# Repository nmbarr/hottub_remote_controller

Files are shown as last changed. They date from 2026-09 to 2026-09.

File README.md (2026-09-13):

# Hot Tub Remote Controller



Hardware and firmware for a remote monitor/controller that taps into a hot
tub's control system, aiming to expose status and control over WiFi instead
of only via the tub's built-in panel.

## Status

Early hardware design phase, **currently mid-pivot**. The tub's topside is a
Balboa VL240, and on GS-series packs that panel is not on an RS485 bus at
all: it is a dumb terminal on a 6-signal harness — four raw button contacts
plus a clock/data pair carrying the 7-segment display bitmap. See
[`docs/wifi.md`](docs/wifi.md#topside-panel-interface).

That invalidated the RS485 design this repo was originally built around.
Superseded and removed:

- `firmware/v1` — the from-scratch UART2 half-duplex driver, `0x7e` framer,
  and Balboa CRC-8. None of it described this tub, and it's been replaced
  by `firmware/esphome-spa`: a vendored, adapted fork of
  [kgstorm/Balboa-GS100-with-VL260-topside](https://github.com/kgstorm/Balboa-GS100-with-VL260-topside)
  (see [`firmware/esphome-spa/README.md`](firmware/esphome-spa/README.md)),
  which already implements the display-tap decode this tub's interface
  needs.
- The MAX3485 in `hardware/esp32-spa` (renamed from `hardware/v1`), and V2's
  plan to interpose between panel and pack. The board no longer sits *in*
  the harness; it hangs off it in parallel.

Still true: the ESP32 DevKitC, the RJ45 breakout so nothing gets spliced,
and the V2 antenna work. `firmware/esphome-spa` talks to Home Assistant
(running on the same Pi) rather than MQTT/Node-RED directly — see its own
README — though Mosquitto/Node-RED may still end up in the picture for
anything without an HA integration, like the planned pH/ORP sensors.

Nothing has been connected to the tub yet. The interface above is confirmed
for kgstorm's GS100; this pack is a Mach 7 (RS-81), and matching it is still
an inference from parts listings — see the read-only check in
[`docs/wifi.md`](docs/wifi.md#still-unconfirmed) before building.

## Hardware

`hardware/esp32-spa` (renamed from `hardware/v1`) contains the KiCad project
for the v1 board:

- **ESP32-DevKitC** as the main controller.
- **MAX3485** RS485 transceiver — **superseded**, see Status. The schematic
  has not been redrawn yet.

What replaces it: a passive tap on the topside harness. Two divided inputs
for the display clock and data, and four optocouplers to bridge the button
contacts without loading or backfeeding the panel, which stays wired in
parallel and has to keep working.

### Hardware diagram

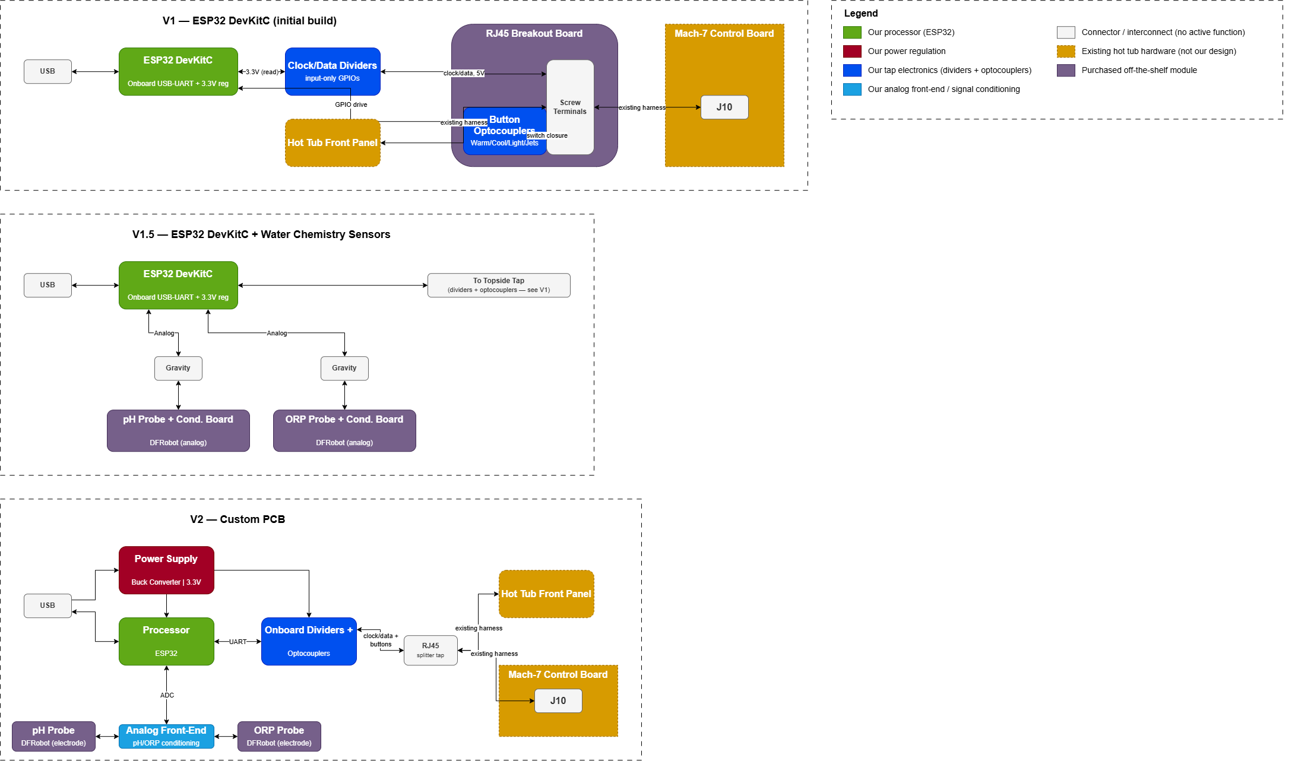
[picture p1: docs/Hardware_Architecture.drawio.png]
Hardware architecture


The three planned board revisions (v1, v1.5, v2 — see the roadmap below).

### Hardware roadmap

The hardware diagram lays out three planned revisions:

- **V1 — ESP32 DevKitC (initial build).** An ESP32 DevKitC (using its
  onboard USB-UART and 3.3V regulator) tapping the topside harness between
  the front panel and the Mach-7 control board, through an off-the-shelf
  RJ45 breakout board and screw terminals — no cutting or splicing of the
  existing harness. Two resistor-divided inputs read the display clock and
  data; four optocouplers bridge the button contacts. Build the read-only
  half first: it needs no optocouplers and touches nothing the pack can act
  on, so it proves the interface before anything can press a button.
- **V1.5 — + water chemistry sensors.** Same V1 hardware and same tap,
  with off-the-shelf DFRobot pH and ORP probes (each with its own analog
  conditioning board) added on, wired into the DevKitC's analog inputs via
  Gravity/JST connectors.
- **V2 — custom PCB.** Replaces the DevKitC with a purpose-built board: an
  ESP32-WROOM-32UE as the processor, a dedicated buck-converter power
  supply, and the dividers and optocouplers onboard. Note this no longer
  needs two RJ45 jacks in series: the board is a parallel tap, not an
  interposer, so one jack on a splitter off the existing harness does the
  job and keeps the panel working if the board is unplugged. The purchased
  DFRobot conditioning boards are also replaced by a custom analog front-end
  that conditions the raw pH and ORP electrodes directly for the ESP32's
  ADC.

#### Antenna

V2 uses the **WROOM-32UE**, the variant with a U.FL connector for an
external antenna, rather than the **-32E** with its PCB trace antenna.
Everything about the two is identical except the antenna, and the deciding
factor is where the board lives: a spa equipment bay is water on all sides,
several inches of foam insulation, a sealed enclosure the board cannot work
without, and an AP that is inside the house through at least one exterior
wall.

Marginal WiFi is a worse outcome here than it looks. The whole design
depends on the ESP32 holding an outbound MQTT connection, so a weak link
does not degrade gracefully — it becomes a board that drops and reconnects,
with `hottub/status` flapping through its LWT. Diagnosing that once the
board is sealed into a box under the tub is miserable.

The decision does not have to be made at layout time. Both modules share a
pad layout — the -32UE is simply shorter, having no antenna section — so a
footprint drawn for the -32E, with the module at the board edge and its
antenna keepout honoured, accepts either. Note that the keepout is a hard
constraint that shapes the board outline (no copper, no pour, no traces on
any layer); getting it wrong detunes the antenna, which presents exactly
like weak WiFi and cannot be fixed without a respin.

For the antenna itself: 2.4GHz only, since that is all the ESP32 speaks,
and a **2–3 dBi omni dipole** rather than something advertising high gain.
Omni antennas buy gain by flattening their pattern into a disc, which
trades away the vertical coverage that matters when the geometry is not
known in advance.

Keep the U.FL pigtail short, 100–150mm. Pigtail coax runs about 1.5 dB/m at
2.4GHz, so a long one gives back more than the antenna gains; use RG316 if
the antenna genuinely needs to be further away. Buy pigtail and antenna as
a matched pair — RP-SMA and SMA are a reversed-gender convention, look
nearly identical, and are easy to mix up.

Placement matters more than any of this. Getting the antenna out of the
foam and outside the enclosure is worth more than an antenna upgrade, and
the bulkhead that gets it there is a hole in a sealed box in a splash zone:
use an IP-rated one with an O-ring, on a face that does not collect drips.

Worth measuring rather than guessing — `esp_wifi_sta_get_ap_info()` reports
RSSI, so candidate placements can be compared directly before anything is
sealed up. Better than −65 dBm is comfortable; worse than −80 is the
reconnect-loop failure mode above.

## IoT architecture diagram

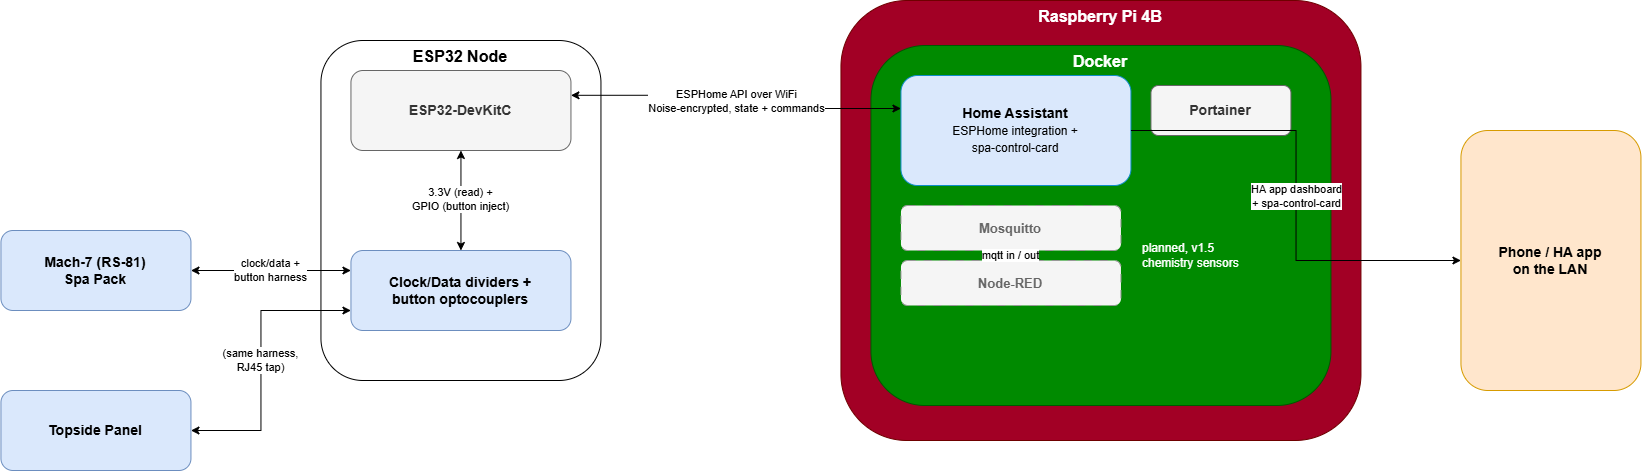
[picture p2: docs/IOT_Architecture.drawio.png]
IoT architecture


The runtime topology: the parallel tap on the harness between the topside
panel and the Mach-7 pack, and the ESP32's Home Assistant API link on the
Pi. Mosquitto/Node-RED are sketched as planned rather than wired up — the
v1.5 chemistry sensors don't have a Home Assistant-native path the way the
panel decode does via `firmware/esphome-spa`, so they may end up going
through MQTT/Node-RED instead once they exist.

## Docs

- [`docs/wifi.md`](docs/wifi.md) — the topside panel interface (connector
  pinout, signal levels, frame format), plus the plan for exposing the tub
  over WiFi via MQTT to a Raspberry Pi running Mosquitto and Node-RED: a v1
  that monitors and controls the tub from the local network, and a v2 that
  adds remote access over a VPN (no firmware change). **Stale on the MQTT
  point** — see `firmware/esphome-spa`'s README for the Home Assistant path
  this device actually takes; the panel-interface reverse-engineering
  (pinout, signal levels, frame format) is unaffected.
- [`docs/wsl-setup.md`](docs/wsl-setup.md) — building and flashing from WSL2:
  forwarding the DevKitC's USB serial port in with usbipd-win, `dialout`
  permissions, and activating this machine's `eim`-installed ESP-IDF.

## Repository layout

```
hardware/esp32-spa/    KiCad schematic and project for the v1 board
firmware/esphome-spa/  ESPHome firmware (fork of kgstorm's), Home Assistant-controlled
Drivers/libdrivers     Submodule of shared, vendor-agnostic sensor drivers
docs/                  Hardware and IoT architecture diagrams and design notes
```

## Firmware

`firmware/esphome-spa` is an ESPHome project — see
[`firmware/esphome-spa/README.md`](firmware/esphome-spa/README.md) for
provenance, build, and Home Assistant setup:

```
pip install esphome
esphome run firmware/esphome-spa/esp32-spa.yaml   # first flash, over USB
```

Target wiring for the topside tap. The panel harness is an 8-pin RJ45; pin
numbering and the signals on it are documented in
[`docs/wifi.md`](docs/wifi.md#connector).

| RJ45 pin | Signal | ESP32 | Via |
| ---: | --- | --- | --- |
| 1 | +5V | `VIN` | measure before connecting |
| 4 | GND | `GND` | — |
| 6 | Clock | GPIO35 | divider, 220Ω series |
| 5 | Display data | GPIO34 | divider |
| 2 | Warm | GPIO25 | optocoupler |
| 8 | Cool | GPIO26 | optocoupler |
| 3 | Light | GPIO27 | optocoupler |
| 7 | Jets/blower | GPIO32 | optocoupler |

Clock and data go on GPIO34/35 because those are input-only, which is the
property you want on the two pins wired to a live panel the firmware must
never drive. They have no internal pull-ups, so pull externally.

The signals are 5V. Divide them: 6.8k/10k lands at 2.98V, with headroom
under the ESP32's 3.6V absolute maximum even if the pack's rail sits high.
Buttons go through a PC817B each, 220Ω on the LED, collector to +5V and
emitter to the button line — wiring and the reasoning behind the values are
in [`docs/wifi.md`](docs/wifi.md#button-injection).

If you're developing in WSL2, the board is attached to Windows and its
serial port has to be forwarded in before `esphome` can see it — see
[`docs/wsl-setup.md`](docs/wsl-setup.md).

## Submodules

This repo uses a git submodule for shared drivers:

```
git submodule update --init --recursive
```

## CI

The `CI` workflow (`.github/workflows/ci.yml`) runs on every PR, on pushes to
`main`, and weekly against `main` (Mondays) to catch drift even when
nothing's changed recently. The split matters: `pull_request` covers proposed
changes and fork PRs, `push` covers what actually lands, and leaving both
unrestricted ran every job twice on the same commit.

A second push to a branch supersedes its in-flight run rather than letting it
finish against a commit nobody is waiting for. `main` is exempt, so each
landed commit keeps a result of its own.

`hardware` runs KiCad's headless checks: ERC on each project's schematic, and
DRC on its board once one exists (v1 and v1.5 are schematic/wiring-only, no
custom PCB — that starts with v2).

`esphome-build` compiles `firmware/esphome-spa/esp32-spa.yaml`, installing
ESPHome fresh each run (its ESP-IDF download is cached across runs) and
supplying the committed `secrets.yaml.example` in place of the gitignored
real `secrets.yaml`; it holds no real secrets and never reaches a board from
CI. This is what catches a vendored-component compile break against a newer
ESPHome release, same as it caught the missing `text_sensor.h` include
upstream needed.

`esphome-build` is the only job gated on what changed: a `changes` job
reports whether `firmware/esphome-spa/**` (or the workflow itself) was
touched, and the build is skipped otherwise. The gate is on the job, never on
the workflow's triggers — see below.

`hardware` is a required status check on `main`, which is why no job has a
paths filter — a required check skipped by a path filter never reports at
all, and GitHub blocks the merge on it forever. Skipping a job with `if:` is
different and safe: the workflow still triggers and the job still reports,
just with a skipped conclusion, which branch protection accepts. That is why
`esphome-build` is gated that way rather than with a paths filter.

A status check's identity comes from the job name, not the workflow file name,
so renaming the file from `kicad-checks.yml` left the required check intact.

The `hardware` job seeds KiCad's default global library tables before running so stock
libraries resolve the same as on a normal install; only error-severity
findings fail the build, and remaining warnings (currently just
`PCM_Espressif`, a library installed locally via KiCad's Plugin & Content
Manager rather than vendored into the repo) print to the log for visibility
but don't block.

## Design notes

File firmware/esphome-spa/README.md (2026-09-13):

# ESPHome fork (experimental)

Replaces `firmware/v1`'s custom `esp-mqtt` firmware (now deleted): instead of
writing the Balboa display decode from scratch, this vendors
[kgstorm/Balboa-GS100-with-VL260-topside][kg] — the same reference
implementation cited in [`docs/wifi.md`](../../docs/wifi.md#reference-implementation) —
and runs it as upstream intended: talking to Home Assistant, controlled from
the HA phone app, rather than through this project's Mosquitto/Node-RED
stack.

**Status: unconfirmed, do not flash yet.** kgstorm's decode is verified
against a GS100 pack with VL200/VL400-series panels. This tub's pack is a
Mach 7 (RS-81); whether it speaks the same protocol as the GS100 is still an
open question — see
[`docs/wifi.md#still-unconfirmed`](../../docs/wifi.md#still-unconfirmed).
Do the scope/logic-analyzer check on RJ45 pins 5/6 before relying on
anything here.

## Provenance

- Upstream: <https://github.com/kgstorm/Balboa-GS100-with-VL260-topside>
- Pinned commit: `044e87d746f30bd3202a3a62683cf3b95865d6b5`
- License: MIT — see `LICENSE.upstream` (copied verbatim from upstream)

Vendored, not pulled live via `external_components: source: github://...`,
so the panel-decode logic (`esp32-spa/inputs/esp32-spa.h`) stays put even if
upstream changes, and this fork's edits are easy to diff against a known
base.

## What was changed vs. upstream

- **`api:` left as-is.** Entities are controlled through Home Assistant and
  the vendored `spa-control-card.js` Lovelace card (see Frontend, below) —
  not MQTT. Home Assistant runs on the Pi alongside Mosquitto (which the
  water-chemistry sensors below still don't need HA for, if that stack ever
  wants them independently).
- **Removed the `update:`/second `ota:` platform** that polled kgstorm's
  hosted `manifest.json` for firmware updates — meaningless once this fork
  diverges from upstream, and undesirable to leave pointed at someone else's
  release feed.
- **Added water chemistry sensors** (`i2c:` + `ads1115` platform entries in
  `sensor:`) for this project's planned pH/ORP probes. These are new
  additions alongside kgstorm's decode, not modifications to it — the
  custom `esp32_spa` component (`esp32-spa/inputs/`) is untouched.
- **GPIO pins left as upstream's** (CLK=35, DATA=34, WARM=25, COOL=26,
  LIGHT=27, PUMP=32) — and these turn out to already match
  `hardware/esp32-spa`'s wiring table (see the root README's Firmware
  section), so no pin remapping was actually needed here.

## What still needs real values, not placeholders

- **pH/ORP calibration** (`calibrate_linear` in `esp32-spa.yaml`) — the
  current `0.0 -> 0.0, 3.0 -> 14.0` mapping is a stand-in shape, not a
  calibration. Needs real two-point buffer-solution readings once a probe
  is on hand.
- **I2C pins** (`sda: GPIO21` / `scl: GPIO22`) — arbitrary defaults, not
  checked against `hardware/esp32-spa`'s actual wiring (the v1.5 chemistry
  sensors aren't on that schematic yet).

## Building

```
pip install esphome   # or the Docker image, see project notes
cp secrets.yaml.example secrets.yaml   # fill in real values
esphome compile esp32-spa.yaml
```

## Home Assistant setup

Home Assistant runs on the Pi, separate from this build step:

1. Run Home Assistant on the Pi — [HA Container](https://www.home-assistant.io/installation/raspberrypi#docker-compose)
   is the lightest fit alongside the existing Mosquitto install; HA OS is
   the alternative if you'd rather give it the whole disk.
2. First flash is over USB (`esphome run esp32-spa.yaml`); after that, HA's
   **ESPHome** integration (Settings → Devices & Services → Add Integration
   → ESPHome) discovers the device on the network via `api:` and handles
   OTA updates from then on — no need to keep running `esphome` by hand.
3. `secrets.yaml`'s `api_key` is the noise-encryption PSK HA and the device
   share; HA will ask for it (or auto-fill it if it discovered the key from
   the device) when you add the integration.

### Frontend

`spa-control-card.js` (vendored from upstream, same commit as everything
else here) is a custom Lovelace card purpose-built for this firmware's
entities:

1. Copy `spa-control-card.js` into HA's `config/www/` folder.
2. In the dashboard you want it on: **⋮ menu → Manage resources → Add
   resource**, URL `/local/spa-control-card.js`, type **JavaScript Module**.
3. **Add Card → Spa Control Card**, or add this YAML directly:

   ```yaml
   type: 'custom:spa-control-card'
   device_name: 'esp32-spa'   # matches esphome: name: in esp32-spa.yaml
   title: 'Hot Tub Control'
   ```

If the card doesn't show up, hard-refresh the dashboard
(Ctrl/Cmd+Shift+R) — HA aggressively caches Lovelace resources.

[kg]: https://github.com/kgstorm/Balboa-GS100-with-VL260-topside

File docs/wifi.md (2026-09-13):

# WiFi access

Goal: view live hot tub status (and, once v1.5's water chemistry sensors are
in, pH/ORP readings) from a phone instead of only via a wired debug
connection, and send commands — starting with the temperature setpoint —
back the other way.

WiFi: the ESP32 has WiFi built into the SoC, so there's no separate WiFi
module or driver to write — connectivity and the MQTT client both come from
ESP-IDF's own `esp_wifi`/`esp-mqtt` components, used directly rather than
vendored into this repo. (This replaces an earlier plan, from when the board
was STM32-based, to drive an external Inventek ISM43362 WiFi module over SPI
via ST's X-CUBE-WIFI1 middleware — moot now that WiFi is native to the
processor.)

## Architecture

Both versions use the same topology; they differ only in *where you can be
standing*. A Raspberry Pi on the LAN acts as the IoT server:

```
  ESP32  <--outbound MQTT-->  Mosquitto  <-->  Node-RED  -->  dashboard
 (clock/data +               (broker,          (flows,        (phone)
  buttons, on the             on the Pi)        logic, UI)
  panel harness)
```

- **Broker**: Mosquitto on the Pi. The ESP32 makes a single outbound
  connection to it and never accepts inbound connections itself — including
  for commands, which arrive over that same outbound connection as
  subscriptions rather than as inbound requests. This is what makes v2's
  remote access possible without ever exposing the board.
- **Logic/UI**: Node-RED on the same Pi, subscribing and publishing through
  `mqtt in`/`mqtt out` nodes. `node-red-dashboard` provides the phone UI
  (gauges for temp/pH/ORP, a slider for the setpoint), so there's no custom
  frontend in this repo and UI changes never require reflashing the board.
- **Firmware side** (stale): this bullet described a from-scratch `esp-mqtt`
  (`mqtt_client`) firmware, declared as a managed component in the
  now-deleted `firmware/v1`. That firmware was replaced by
  `firmware/esphome-spa` — a vendored ESPHome fork that talks to Home
  Assistant's native API instead, not MQTT. See its own README.

## Topside panel interface

The topside is a **Balboa VL240**: a stock Balboa ValueLine keypad, where
"AquaRest"/"Dream Maker" is only the self-adhesive overlay (DreamMaker p/n
407016) stuck on the front. It reaches the pack over an 8-pin RJ45 on a 7ft
cord.

That harness is **not** an RS485 packet bus, and that fact shapes everything
below. On GS-series packs a VL2xx/VL4xx topside is a dumb terminal: the pack
owns all the logic and clocks the panel's 7-segment glass directly, while the
four membrane switches return to the pack as raw contacts. There is no
addressing, no framing, no CRC, and nothing for this board to transmit.

This supersedes an earlier plan built on the reverse-engineered Balboa
RS485 protocol ([ccutrer/balboa_worldwide_app][bwa]) and a MAX3485
transceiver interposed between panel and pack. That protocol is real, but it
belongs to Balboa's BP-series systems; it is not what this pack speaks to
this panel.

[bwa]: https://github.com/ccutrer/balboa_worldwide_app

### Connector

| RJ45 pin | Function | Direction |
| ---: | --- | --- |
| 1 | VIN | power |
| 2 | Warm button | ESP32 → pack |
| 3 | Light button | ESP32 → pack |
| 4 | GND | — |
| 5 | Display data | pack → ESP32 |
| 6 | Clock | pack → ESP32 |
| 7 | Jets/blower button | ESP32 → pack |
| 8 | Cool button | ESP32 → pack |

Six GPIO, not four: four to press buttons and two to read the display.
Dropping pins 5 and 6 would leave control with no monitoring — no water
temp, no setpoint, no heater state, no error codes, and nothing to put on a
dashboard.

Pin 7 is whichever function the overlay prints on the fourth switch; the
AquaRest overlay says blower where Balboa's stock one says jets. Same
switch either way.

### Electrical

RJ45 pin 1 is **+5V** — kgstorm's wiring diagram labels it outright, and he
feeds the DevKit's VIN from it. Measure it before trusting that on this pack.

- **Clock and data** are 5V and need dividing down. His two sources disagree
  slightly and both sit tighter than they need to:

  | Source | Top / bottom | At the GPIO |
  | --- | --- | --- |
  | wiring diagram | 2.2k / 4.7k | 3.41V |
  | PCB BOM (R1–R4) | 4.7k / 10k | 3.40V |
  | **used here** | **6.8k / 10k** | **2.98V** |

  The ESP32's absolute maximum is 3.6V, so 3.4V works — but a rail sitting
  at 5.25V puts it at 3.58V. 6.8k/10k keeps the 10k leg and buys ~0.6V of
  headroom for the price of one resistor value.
- **Use input-only GPIOs for clock and data** (GPIO34–39). They have no
  internal pull-ups, so pull externally (~10k). Keep a small series resistor
  (100–220Ω) on each for edge-ringing and ESD — not current limiting — and
  especially on the clock line, which takes an interrupt on every edge.

### Button injection

Four **PC817B** optocouplers, one per button. The transistor goes across the
same two points the membrane switch bridges: you are adding a second switch
in parallel with the panel's, not driving the line.

| PC817 pin | | Connects to |
| ---: | --- | --- |
| 1 | Anode | ESP32 GPIO, through 220Ω |
| 2 | Cathode | ESP32 GND |
| 3 | Emitter | RJ45 button line |
| 4 | Collector | RJ45 pin 1 (+5V) |

Pin 1 is marked with a dot or chamfer.

| Opto | GPIO | Emitter → RJ45 | Button |
| --- | --- | --- | --- |
| U1 | 25 | pin 2 | Warm |
| U2 | 26 | pin 8 | Cool |
| U3 | 27 | pin 3 | Light |
| U4 | 32 | pin 7 | Jets/blower |

**Orientation is easy to get backwards.** Collector to +5V, emitter to the
button line, never the reverse. That makes it an emitter follower, which
will not hard-saturate — but the button line is a high-impedance divider
node (it idles at 2.5V off a 5V rail), and a PC817B at ~10mA of LED current
sources far more than that node needs. It pulls to within a couple hundred
mV of 5V.

**220Ω on the LED, not 100Ω.** His two sources disagree here too, and the
breadboard value is the right one: 220Ω gives (3.3 − 1.15)/220 ≈ 9.8mA,
where the PCB's 100Ω gives 21mA — past the ESP32's 20mA recommended per-pin
source current, for no benefit.

**Specify the B rank.** PC817B is CTR 130–260%, so 10mA in yields 13–26mA
out. Ungraded PC817 is 50–600%; at the bottom of that spread the part that
gets soldered behaves differently from the one that was prototyped with.

#### No resistor between +5V and the collector

Deliberately. His PCB has none — all ten resistors are accounted for as two
dividers, two signal series and four LED series.

The membrane switch being emulated is a bare short, so whatever current
flows on a real press is what the pack was designed to sink; putting a
resistor in the path makes the injected press electrically *different* from
a real one. Current is set by the load anyway — roughly (5V − Vce) over the
pack's pull-down, on the order of 0.5mA for a 10k leg, against the PC817's
50mA maximum.

Headroom is the scarce resource. There is only 2.5V between idle and
pressed, the emitter follower already eats some of it, and the pack's logic
threshold is unknown. A series resistor stacks another drop onto that budget
and buys the worst failure mode available: presses that work on the bench
and go intermittent cold, wet, or once contact resistance has crept.

**Measure before committing this to a schematic.** With the panel plugged
in, put a milliammeter between a button line and +5V — that is a real press,
current-metered. Sub-milliamp is expected and confirms the above. Tens of mA
means the topology is not what is documented here; stop and re-probe. Check
the idle level on all four button pins while there rather than assuming 2.5V
across the board.

#### Isolation, or the lack of it

This circuit is **not galvanically isolated**. The ESP32 takes VIN from RJ45
pin 1 and ground from pin 4, so ESP32 ground *is* spa ground. The optos buy
a floating contact, not isolation: a switch that works regardless of the
levels on either side, cannot backfeed 5V into a 3.3V pin, and cannot assert
a button from a floating or bootstrapping GPIO. Those are real and are most
of the value — but they are not isolation, and the distinction matters for a
board in a wet bay sharing a ground with a heater.

Real isolation means powering the ESP32 from its own supply and leaving RJ45
pins 1 and 4 off the board entirely. The catch is that the clock/data
dividers then lose their ground reference, so those two signals need optos
or a digital isolator as well and the divider approach stops working. That
is a fork worth deciding before layout, not after.

A stuck-on opto is not the reason to add parts. It is electrically
indistinguishable from a stuck membrane switch, which is a failure the pack
already has to tolerate. The realistic fault is a firmware bug parking a
press, and the fix for that is in firmware: bound every press with a hard
maximum duration enforced by a timer that is not the code path that started
the press. GPIO25/26/27/32 are boot-safe, which is why they were chosen —
but confirm none of them float high before `app_main` runs, because an opto
does not care whether the level was intentional.

### Frame format

Synchronous and clocked, so there is no baud rate to get wrong:

| | |
| --- | --- |
| Clock | ~16µs high, ~21µs low (~27kHz) |
| Frame | 24 bits, MSB first |
| Frame gap | ~19ms — i.e. ~50Hz, because this is a display refresh, not a message |

The 24 bits split into four fields:

| Field | Bits | Meaning |
| --- | ---: | --- |
| `p1` | 7 | bits 5 and 4 both set = hundreds digit `1` (temp ≥ 100°F); **bit 2 = heater on**; `(p1 & 0x4B) == 0` is the validity check |
| `p2` | 7 | tens digit, raw 7-segment bitmap |
| `p3` | 7 | ones digit, raw 7-segment bitmap |
| `p4` | 3 | bit 2 = pump/jets, bit 1 = light, bit 0 always 0 |

Decoding means reverse-mapping segment patterns to characters. This is
reading the display, not parsing a protocol, and the consequences run
through the whole design: error codes arrive as the two-character string the
panel shows (`HH`, `FL`, …), and heat mode has to be caught as `St`/`Ec`/`SL`
flash past during mode selection. Anything the panel cannot display does not
exist to this firmware.

Because it is a display, frames also repeat at 50Hz and flicker through
transient states. Decoded values need a stability filter — N identical
consecutive frames before publishing — rather than being trusted per frame.

### Reference implementation

[kgstorm/Balboa-GS100-with-VL260-topside][kg] (ESPHome, ESP32 DevKit V1) is
the closest prior art: same interface, tested against VL200- and VL400-series
panels on a GS100, with a PCB and an enclosure in-tree. [kgstorm/Balboa-GS5xx][kg5]
covers panels with a single Temp button instead of Warm/Cool.
[MagnusPer/Balboa-GS510SZ][mp] is an independent implementation for the
GS510SZ and useful as a second opinion on the decode.

[kg]: https://github.com/kgstorm/Balboa-GS100-with-VL260-topside
[kg5]: https://github.com/kgstorm/Balboa-GS5xx
[mp]: https://github.com/MagnusPer/Balboa-GS510SZ

### Still unconfirmed

kgstorm's pack is a GS100; this one is a Mach 7 (RS-81), sold as a "Mach 7
Balboa 56795 Pack". The VL240 is listed as compatible with GS100, GS500Z,
GS501Z and GS511Z, which is good evidence they are the same family — but it
is still evidence from parts listings, which is exactly the kind of
inference that produced the RS485 plan this section replaces.

Confirm on the hardware before building anything:

- Scope or logic-analyze RJ45 pins 5 and 6 and look for 24-bit bursts
  separated by ~19ms gaps. Read-only and non-destructive.
- Measure pin 1 before wiring it to the DevKitC's VIN.
- Confirm the button idle/pressed levels on pins 2, 3, 7 and 8 rather than
  assuming 2.5V/5V.

### Consequence: the setpoint is a closed loop

The pack exposes no way to *write* a setpoint. Warm and Cool step it, and
while stepping, the display shows the set temperature instead of the
measured one. So setting an absolute temperature is a loop in firmware:
press Cool to make the pack reveal the current setpoint, read it back off
the display feed, step toward the target, confirm. kgstorm re-reads the
setpoint every 6 hours with a Cool→Light sequence for the same reason — left
alone, the display only ever shows measured temp.

This does not change the MQTT contract below; `hottub/cmd/setpoint` stays
absolute. It moves the work into the firmware, where it belongs.

## Topic map

| Topic | Dir | Retain | QoS | Payload | Version |
| --- | --- | --- | --- | --- | --- |
| `hottub/status` | ESP32 → | yes | 1 | `online` / `offline` (LWT) | v1 |
| `hottub/state` | ESP32 → | yes | 0 | JSON status blob | v1 |
| `hottub/cmd/setpoint` | → ESP32 | **no** | 1 | setpoint in °F, e.g. `102` | v1 |
| `hottub/cmd/light` | → ESP32 | **no** | 1 | `on` / `off` / `toggle` | v1 |
| `hottub/cmd/jets` | → ESP32 | **no** | 1 | `on` / `off` / `toggle` | v1 |

`light` and `jets` map to single button presses, so they are cheap. The
panel reports both back in `p4`, which is what makes `on`/`off` (rather than
only `toggle`) implementable: read the current state, press only if it
differs.

## v1 — local monitoring and control

Scope: the board joins the local WiFi network, publishes current status to
the broker, and accepts commands from it. Node-RED renders the dashboard and
drives the controls for a phone on the same network. No internet routing.

### Telemetry

- **Transport**: MQTT publish to Mosquitto. The board publishes; it does not
  serve. This is strictly less firmware than an on-device HTTP server — no
  request handlers, no connection handling, no client tracking, since the
  broker does all of that.
- **Push, not poll**: the panel task publishes `hottub/state` when a decoded
  value changes and clears its stability filter. Because the topic is
  retained, a phone or a restarted Node-RED gets current values immediately
  on connect rather than waiting for the next update. Note that the display
  feed itself arrives at ~50Hz; that cadence is a refresh rate, not a
  publish rate.
- **No shared "latest reading" state needed** *in this direction*. The task
  that produces the reading is the task that publishes it, so there's no
  struct-behind-a-mutex handoff between a decoder loop and a server task.
  (This was an open question under the earlier HTTP design; the MQTT shape
  removes it for telemetry. Commands do need a handoff — see below.)
- **Payload**: one JSON blob on `hottub/state`, not a topic per field. Keeps
  the firmware to a single serializer; Node-RED splits fields out for the
  dashboard with a `json` node.
  ```
  hottub/state  {"water_temp_F":102.4,"ph":7.4,...}
  ```
- **LWT** on `hottub/status` so the dashboard can distinguish live readings
  from stale ones left behind by a board that dropped off. Keepalive is set
  to 30s rather than the 120s default: a broker waits 1.5x keepalive before
  declaring a client dead, so the default leaves the dashboard showing a
  confident `online` for three minutes after the board stops existing. Low
  enough to be useful, high enough that a brief WiFi glitch does not flap it.
  Note the LWT only covers vanishing — the board publishes `online` itself on
  every connect, retained, or the status stays `offline` after any reconnect.

### Commands

- **Commands are absolute, not relative.** `setpoint = 102`, never
  `temp_up`. QoS 1 is at-least-once, so a redelivered relative command would
  silently apply twice. This matters more here than it would on a packet
  bus: the *mechanism* underneath is relative — stepping Warm and Cool — so
  the firmware is the only thing standing between an at-least-once delivery
  and a tub that drifts a degree every redelivery. Absolute intent in,
  closed-loop stepping inside, never relative commands over the wire.
- **Never retain command topics.** A retained command is redelivered to the
  ESP32 on every reconnect, replaying the last setpoint change after every
  power blip. Publish commands with `retain=false`. (State stays retained —
  the asymmetry is deliberate.)
- **The MQTT callback does not press buttons.** Applying a setpoint is a
  multi-second sequence — press, hold ~200ms, release, wait for the display
  to settle, read, decide, repeat — so it cannot run inside an `esp-mqtt`
  event handler. The handler validates the command, hands the target to the
  panel task, and returns; that task owns the button GPIOs and runs the
  loop. This is the one place the two tasks share state — a pending-command
  slot in the command direction, guarded by a mutex or written as a queue —
  which is why the telemetry-direction claim above is scoped the way it is.
- **One writer for the buttons.** The panel task owning all four GPIOs is
  not just tidiness: a setpoint walk in progress and a stray `cmd/light`
  both pressing buttons would interleave presses into the pack and desync
  the walk from the display it is reading. Serialise commands in that task's
  queue.
- **Command → apply → echo.** The command topic is not state. Once the panel
  task has pressed the buttons, what feeds `hottub/state` is the pack's own
  display output, decoded back off pins 5 and 6. The dashboard binds to the
  state topic, so a rejected or failed command visibly doesn't take rather
  than showing optimistic UI. The echo is unusually trustworthy here: it is
  literally what the tub is showing on its own panel, not a status field the
  firmware asked for.
- **The ESP32 is the authority.** Every inbound command is range- and
  sanity-checked in firmware before it reaches the bus — the broker will
  happily deliver a typo'd `mosquitto_pub` of `999`; the protocol's own
  bounds are 80–104°F in high range. Note also that the
  Mach-7 pack keeps its own thermostat and high-limit logic, and the tub's
  own panel keeps working regardless, so neither the Pi nor this board sits
  in a safety-critical path. That's not a reason to skip the checks — and
  a bounds check is also what stops a bad target turning into an unbounded
  press loop against a setpoint that has already hit the pack's own limit.
- **Resubscribe on every `MQTT_EVENT_CONNECTED`**, unless clean-session is
  disabled — subscriptions don't survive a clean-session reconnect.

### Addressing, credentials and auth

- **Addressing**: the ESP32 needs no fixed address of its own, since nothing
  connects to it — only the *broker* needs a stable address (static IP or
  DHCP reservation on the Pi), hardcoded at build time.
- **Credentials**: WiFi SSID/password and broker host/user/password
  hardcoded at build time.
- **Auth, even on the LAN**: because v1 can *change the tub's setpoint*,
  "everyone on my WiFi is trusted" is a weaker assumption than it was for a
  read-only version — a guest on the WiFi, or anything compromised on it,
  can drive the tub. Set a per-device username/password on Mosquitto and
  turn on Node-RED's dashboard auth (`httpNodeAuth`) and editor auth
  (`adminAuth`) from the start. They're config, not code, and v2 needs them
  anyway.

Explicit non-goals for v1: access from outside the local network, TLS,
history/logging.

### Open implementation questions

- **Credentials in git**: hardcoding at build time is fine, but not directly
  in a tracked file. Use a gitignored header (e.g. `wifi_credentials.h`,
  with a checked-in `.example` template) rather than literal `#define`s in
  tracked source.
- **Publish cadence**: on change, or rate-limited? Publishing at the display's
  ~50Hz refresh is obviously wrong, and water temp barely moves — but
  on-change needs a deadband so noise on the pH ADC doesn't publish
  continuously, and the display's own flicker is already handled by the
  stability filter rather than by the publish rule.
- **Broker unreachable**: `esp-mqtt` reconnects on its own, but decide what
  the panel task does meanwhile — almost certainly keep decoding and drop
  updates rather than buffering, since stale readings have no value.
- **Stability thresholds**: how many identical consecutive frames before a
  value is trusted, and how long a transient `0x00` counts as "in set mode".
  kgstorm uses 3 frames and a 2s set-mode timeout; both are tuned against a
  GS100 and are worth re-measuring here rather than copying.
- **Which commands beyond setpoint**: the panel has four buttons, so the
  reachable command set is exactly what those four buttons can drive,
  including their press-and-hold and multi-press sequences. Filter cycle and
  heat mode are reachable but only through timed sequences (kgstorm reads
  mode with Cool→Light) — decide whether the added state machine is worth it
  for v1.

### Implementation order within v1

Telemetry first, commands second — and here that ordering is structural
rather than just prudent. The setpoint command *depends* on the decoder: the
closed loop cannot step toward a target without reading the setpoint back
off the display. A read-only firmware is not merely the safe first step, it
is the prerequisite.

It is also the cheap first step. Decoding requires only pins 5 and 6 —
two inputs and a divider, no optocouplers, no connection to anything the
pack can act on — so the entire protocol assumption can be proved or
disproved before a single button line is wired. Get `hottub/state`
publishing real water temp, then wire the buttons.

## v2 — remote access

Scope: reach the same dashboard and the same controls from outside the LAN.

Because v1 already put the broker in the middle and the command path
through it, **v2 requires no firmware change at all** — the ESP32 is
feature-complete at v1. This is a Pi deployment step, not a board revision.

Decisions:
- **Remote access**: reach the Pi over a VPN (Tailscale/WireGuard) rather
  than forwarding any port. Nothing — not 1883, not the Node-RED dashboard —
  is published to the open internet. The ESP32's exposure does not change:
  it still only makes an outbound connection to a LAN broker.
- **TLS**: optional on-LAN given the VPN boundary; if added, the ESP32
  bundles the CA cert. This is the one item that would touch firmware.
- **Auth**: already in place from v1, which is the point of doing it there.

Open question:
- **History/logging**: not scoped. Node-RED can fan `hottub/state` out to
  InfluxDB/SQLite for graphs and alerting ("pH drifted", "heater on 6h")
  with no firmware change, whenever it's wanted.

## Rejected: on-device HTTP server

An earlier version of this plan had v1 serving JSON from an on-device
`esp_http_server` endpoint (`GET /status`), polled by the phone, with MQTT
arriving only in v2. Dropped, because it made the v1→v2 step a transport
rewrite rather than a scope increase, and because it was the more complex of
the two for v1's own goal: an HTTP server needs request handlers and shared
state between the server and panel tasks, where publishing needs neither.

It also could not have carried v1's command path: taking commands over HTTP
means accepting inbound connections to the board, which is exactly what the
broker-in-the-middle design exists to avoid.

A small `/status` endpoint could still be added later as a Pi-independent
debug view. It isn't needed for bring-up — UART logging covers that — so
it's not scoped here.

## Consequences

- **A second box is in the chain.** Both monitoring *and* control now depend
  on the Pi staying up — boot it from an SSD rather than an SD card. The
  tub's own panel keeps working regardless, by design, so the failure mode
  is "no remote control", not "no control".

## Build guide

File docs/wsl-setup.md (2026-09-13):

# Building and flashing from WSL

Development happens in WSL2 (Ubuntu 24.04) on a Windows host. The ESP32
DevKitC plugs into the Windows machine, so its USB serial port has to be
forwarded into WSL before `esphome` can see it. This note records that
forwarding setup and an environment gotcha that cost time the first time
around.

## Forwarding the board into WSL

WSL2 has no native USB passthrough; USB devices are attached over the
network with USB/IP. The WSL kernel already ships the pieces needed to
receive them — `vhci-hcd` plus the `cp210x`, `ch341` and `ftdi_sio` serial
drivers — so nothing has to be installed or built on the Linux side. All the
setup is on Windows.

Install [usbipd-win](https://github.com/dorssel/usbipd-win) once, from an
**administrator** PowerShell:

```powershell
winget install --interactive --exact dorssel.usbipd-win
```

Then find the board's bus ID:

```powershell
usbipd list
```

The DevKitC appears as its USB-serial bridge, not as "ESP32" — `Silicon Labs
CP210x UART Bridge` on a genuine board, `USB-SERIAL CH340` on clones. (An
S3/C3 using the SoC's native USB would instead show as `USB JTAG/serial debug
unit`.) Note the `BUSID`, e.g. `2-4`.

Share the device, then attach it:

```powershell
usbipd bind --busid 2-4          # administrator; persists across reboots
usbipd attach --wsl --busid 2-4  # ordinary shell; does NOT persist
```

**`bind` is one-time. `attach` is not** — re-run it after every unplug/replug
and after every Windows reboot. This is the usual reason `/dev/ttyUSB0`
vanishes mid-session.

In WSL the board then shows up as `/dev/ttyUSB0` (CP210x/CH340; a native-USB
part would be `/dev/ttyACM0`).

## Serial port permissions

`/dev/ttyUSB0` is owned by `root:dialout`, so a user outside that group gets
permission denied even after a successful attach:

```bash
sudo usermod -aG dialout $USER
```

Group membership is only picked up by new logins, and in WSL that means
restarting the distro — run `wsl --shutdown` from Windows and reopen the
terminal. (`newgrp dialout` works for a single shell if you'd rather not.)

## Verifying the chain

Before blaming the firmware, confirm the host can reach the chip at all.
`chip-id` only reads:

```console
$ esptool --port /dev/ttyUSB0 chip-id
Chip type:          ESP32-D0WD-V3 (revision v3.1)
Features:           Wi-Fi, BT, Dual Core + LP Core, 240MHz, ...
Crystal frequency:  40MHz
MAC:                44:1d:64:4f:5b:c8
```

A D0WD-V3 is the plain ESP32, matching `board: esp32dev` in
`firmware/esphome-spa/esp32-spa.yaml`. Because the DevKitC wires DTR/RTS to
EN/GPIO0, esptool resets the board into and out of the bootloader by itself —
there's no need to hold BOOT while flashing.

```bash
esphome run firmware/esphome-spa/esp32-spa.yaml -p /dev/ttyUSB0
```

## Troubleshooting

- **`/dev/ttyUSB0` missing** — the attach lapsed. Re-run `usbipd attach --wsl
  --busid 2-4`.
- **Permission denied on the port** — not in `dialout`, or in it but the
  shell predates the change. `groups` tells you which.
- **Attach fails, or the port drops during a flash** — something on the
  Windows side has the COM port open. Close Arduino IDE, PuTTY, or a VS Code
  serial monitor and retry.
- **usbipd reports the device shared but attach errors about drivers** —
  `usbipd unbind --busid 2-4`, then `usbipd bind --force --busid 2-4`.

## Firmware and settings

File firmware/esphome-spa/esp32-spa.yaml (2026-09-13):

# Forked from kgstorm/Balboa-GS100-with-VL260-topside (MIT license, see
# ../LICENSE.upstream), pinned to upstream commit 044e87d746f30bd3202a3a62683cf3b95865d6b5.
# api: is left as upstream's — this project now runs Home Assistant on the
# Pi and uses their spa-control-card.js Lovelace card, so there's no reason
# to route through MQTT instead. Extended with pH/ORP sensing. See
# ../README.md.

substitutions:
  version: "0.1"

esphome:
  name: esp32-spa
  friendly_name: esp32-spa
  project:
    name: "nmbarr.esp32-spa"
    version: ${version}

  on_boot:
    priority: -100
    then:
      - delay: 35s
      - script.execute: spa_mode_boot_read
      - script.wait: spa_mode_boot_read
      - delay: 25s
      - script.execute: filter_cycle_read

esp32:
  board: esp32dev
  framework:
    type: esp-idf

# Enable Home Assistant API
api:
  encryption:
    key: !secret api_key

ota:
  - platform: esphome
    password: !secret ota_password

wifi:
  # Enable fallback hotspot (captive portal) in case wifi connection fails
  ap:
    ssid: "Esp32-Spa Fallback Hotspot"
    password: !secret ap_password

captive_portal:

logger:

globals:
  - id: display_is_fahrenheit
    type: bool
    restore_value: true
    initial_value: 'false'

  - id: spa_mode_target
    type: std::string
    restore_value: false
    initial_value: '""'

  - id: filter_cycle_target
    type: std::string
    restore_value: false
    initial_value: '""'

external_components:
  - source: esp32-spa

text_sensor:
  - platform: inputs
    parent_id: display_handler
    type: error_code
    name: "Spa Error Code"

  - platform: inputs
    parent_id: display_handler
    type: spa_mode
    id: spa_mode_state
    name: "Spa Mode"
    on_value:
      - if:
          condition:
            not:
              script.is_running: spa_mode_worker
          then:
            - lambda: |-
                if (x == "Standard" || x == "Economy" || x == "Sleep") {
                  id(spa_heating_mode).publish_state(x);
                  id(spa_mode_target) = x;
                }

  - platform: inputs
    parent_id: display_handler
    type: filter_cycle
    id: spa_filter_cycle_state
    name: "Spa Filter Cycle State"
    on_value:
      - if:
          condition:
            not:
              script.is_running: filter_cycle_worker
          then:
            - lambda: |-
                if (x == "F1" || x == "F2" || x == "F3" || x == "F4" ||
                    x == "F5" || x == "F6" || x == "F7" || x == "F8") {
                  id(spa_filter_cycle).publish_state(x);
                  id(filter_cycle_target) = x;
                }

# I2C bus for the water-chemistry ADC. Not part of kgstorm's board — added
# for this project's v1.5 pH/ORP sensors. Confirm SDA/SCL pins against the
# actual v1.5 hardware before flashing; these are placeholders.
i2c:
  sda: GPIO21
  scl: GPIO22

ads1115:
  - address: 0x48
    id: chem_adc

# ===== HOT TUB DISPLAY INPUTS =====
sensor:
  - platform: inputs
    id: display_handler
    measured_temp:
      name: "Spa Measured Temp"
      id: spa_measured_temp
      unit_of_measurement: "°C"
      accuracy_decimals: 1
      device_class: temperature
      filters:
        - lambda: |-
            if (id(display_is_fahrenheit)) return (x - 32.0f) * 5.0f / 9.0f;
            return x;
    set_temp:
      name: "Spa Set Temp"
      id: spa_set_temp
      unit_of_measurement: "°C"
      accuracy_decimals: 1
      device_class: temperature
      filters:
        - lambda: |-
            if (id(display_is_fahrenheit)) return (x - 32.0f) * 5.0f / 9.0f;
            return x;

  # ===== WATER CHEMISTRY (added for this project, not part of upstream) =====
  # Placeholder calibration — needs real two-point buffer-solution readings
  # for the actual probe once it's on hand. Do not trust these values.
  - platform: ads1115
    ads1115_id: chem_adc
    multiplexer: 'A0_GND'
    gain: 6.144
    name: "Spa pH"
    unit_of_measurement: "pH"
    accuracy_decimals: 2
    update_interval: 10s
    filters:
      - calibrate_linear:
          - 0.0 -> 0.0
          - 3.0 -> 14.0

  - platform: ads1115
    ads1115_id: chem_adc
    multiplexer: 'A1_GND'
    gain: 6.144
    name: "Spa ORP"
    unit_of_measurement: "mV"
    accuracy_decimals: 0
    update_interval: 10s

binary_sensor:
  - platform: inputs
    parent_id: display_handler
    type: heater
    name: "Spa Heater Status"
  - platform: inputs
    parent_id: display_handler
    type: pump
    name: "Spa Pump Status"
  - platform: inputs
    parent_id: display_handler
    type: light
    name: "Spa Light Status"
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

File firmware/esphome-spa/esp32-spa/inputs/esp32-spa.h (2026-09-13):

#pragma once

#include "esphome.h"
#include "esphome/core/log.h"
#include "esphome/components/sensor/sensor.h"  // ensure Sensor base class is available
#include "esphome/components/text_sensor/text_sensor.h"  // full TextSensor definition: publish_state() is called below, a forward declaration isn't enough on current ESPHome
#include <string>
#include <utility>

// Forward-declare binary sensor to avoid requiring its header at this point
namespace esphome { namespace binary_sensor { class BinarySensor; } }

// ESP-IDF / FreeRTOS headers
#include "driver/gpio.h"
#include "freertos/FreeRTOS.h"
#include "freertos/portmacro.h"
#include "esp_timer.h"

// Forward declaration of C ISR wrapper (defined after the namespace)
extern "C" void esp32_spa_isr_wrapper(void* arg);

static const char *TAG = "esp32-spa";

// ===== PIN DEFINITIONS =====
// Using input-only GPIOs on ESP32: CLK=GPIO35, DATA=GPIO34
// Note: GPIO34/35 are input-only and do NOT support internal pull-ups; use external pull resistors (e.g., 10k) and a small series resistor on the clock (~47-220 ohm).
static const uint8_t CLK_PIN  = 35;  // Clock (input-only)
static const uint8_t DATA_PIN = 34;  // Data (input-only)

// Button output pins used to inject presses. These are boot-safe GPIOs and match
// the values in `esp32-spa.yaml` (Warm=25, Cool=26, Lights=27, Pumps=32).
#define PIN_WRITE_BTN1 25  // Warm
#define PIN_WRITE_BTN2 26  // Cool
#define PIN_WRITE_BTN3 27  // Lights
#define PIN_WRITE_PUMP 32  // Pumps

namespace esp32_spa {

class HotTubDisplaySensor : public esphome::Component, public esphome::sensor::Sensor {
 public:
  // ---- Shared with ISR ----
  volatile uint32_t shift_reg = 0;
  volatile uint8_t bit_count = 0;
  volatile bool frame_ready = false;
  // Note: removed time-based gap detection in ISR to avoid calling non-IRAM functions from ISR

  // ---- Publish control ----
  uint32_t last_publish_time = 0;
  uint32_t last_published_value = 0;
  uint8_t  last_published_bits = 24;
  bool first_publish = true;
  volatile bool last_frame_valid = false;  // becomes true when a frame passes the checksum and is published
  volatile uint32_t completed_frame = 0;   // frame data saved by ISR pending loop() read
  volatile uint8_t  completed_bits  = 0;   // bit count of completed_frame

  // Remember last decoded values for change detection
  int16_t last_measured_temp = -1;  // -1 = unknown
  int16_t last_set_temp = -1;       // -1 = unknown
  int16_t set_temp_potential = -1;  // candidate for set temp
  uint32_t last_zero_seen_time = 0; // last time we saw 0x00 in p2/p3
  uint32_t last_candidate_temp_time = 0; // last time we saw a candidate temp while in set mode
  bool in_set_mode = false;         // true when we've seen 0x00 recently

  // Pending measured temp publish (to avoid misreading brief set-mode flashes as measured temp)
  int16_t pending_measured_temp = -1;        // -1 = none pending
  uint32_t pending_measured_since = 0;       // time when pending started (ms)
  static constexpr uint32_t MEASURE_PUBLISH_DELAY_MS = 500;  // delay before publishing measured temp (ms)

  // Stability tracking (counters and candidates)
  int16_t candidate_temp = -2; uint8_t stable_temp = 0;
  bool candidate_is_zero = false; uint8_t stable_zero = 0;
  // Heater stability (derived from bit5 of p1)
  int8_t candidate_heater = -2; uint8_t stable_heater = 0;
  // Pump & light stability (derived from p4 bits)
  int8_t candidate_pump = -1; uint8_t stable_pump = 0;
  int8_t candidate_light = -1; uint8_t stable_light = 0;

  // Sensors for temperature readings
  esphome::sensor::Sensor *measured_temp_sensor_ = nullptr;
  esphome::sensor::Sensor *set_temp_sensor_ = nullptr;
  // Text sensor for error codes
  esphome::text_sensor::TextSensor *error_text_sensor_ = nullptr;

  // Binary sensors for discrete states
  esphome::binary_sensor::BinarySensor *heater_sensor_ = nullptr;  // derived from p1 bit5
  esphome::binary_sensor::BinarySensor *pump_sensor_ = nullptr;    // derived from p4 bit0
  esphome::binary_sensor::BinarySensor *light_sensor_ = nullptr;   // derived from p4 bit1

  // Set to true when any valid 24-bit (p4-containing) frame is decoded; pump/light only published after this
  bool seen_p4_ = false;

  // Last published discrete states
  int8_t last_heater = -1;  // -1=unknown, otherwise 0/1
  int8_t last_pump = -1;    // -1=unknown, otherwise 0/1
  int8_t last_light = -1;   // -1=unknown, otherwise 0/1
  // Last published error code (string)
  std::string last_error_code_ = "";
  // Error code stability tracking
  std::string candidate_error = ""; uint8_t stable_error = 0;

  // Spa mode text sensor and state
  esphome::text_sensor::TextSensor *spa_mode_text_sensor_ = nullptr;
  std::string last_mode_ = "";
  std::string candidate_mode_ = "";
  uint8_t stable_mode_ = 0;
  static constexpr uint8_t MODE_STABLE_THRESHOLD = 3;

  // Filter cycle text sensor and state (F + digit)
  esphome::text_sensor::TextSensor *filter_cycle_text_sensor_ = nullptr;
  std::string last_filter_cycle_ = "";
  std::string candidate_filter_cycle_ = "";
  uint8_t stable_filter_cycle_ = 0;
  static constexpr uint8_t FILTER_STABLE_THRESHOLD = 3;

  static constexpr uint32_t HEARTBEAT_MS = 30000;  // heartbeat every 30s (publish if unchanged)
  // Gap threshold (ms) to consider the start of a new frame (use ~15ms to match ~19ms observed gap)
  static constexpr uint32_t FRAME_GAP_MS =5;
  static constexpr uint32_t FRAME_GAP_US = FRAME_GAP_MS * 1000;

  // Stability filtering: require this many consecutive identical decoded frames before publishing
  // Increased to 2 to reduce spurious publishes from brief noise
  static constexpr uint8_t STABLE_THRESHOLD = 3;
  static constexpr uint8_t PUMP_STABLE_THRESHOLD = 3;  // pump requires 3 repeats to be considered stable
  // Error codes are noisier — require more repeats to consider stable
  static constexpr uint8_t ERROR_STABLE_THRESHOLD = 3;
  static constexpr uint32_t SET_MODE_TIMEOUT_MS = 2000;  // 2 seconds without 0x00 = exit set mode
  static constexpr uint32_t HEATER_OFF_TIMEOUT_MS = 1000; // heater must be off for 1s before clearing

  // Timestamp to track when heater bit last went low while heater was on
  uint32_t last_heater_off_time = 0;
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

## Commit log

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2026-09-06 Remove STM32-specific firmware, build config, and CubeIDE tooling
    Migrating to ESP32 (see docs/Architecture.drawio); the STM32L4
    CubeMX-generated sources, HAL/CMSIS drivers, linker/startup files,
    CMake build config, and STM32CubeIDE settings no longer apply. A new
    ESP-IDF build will replace this separately.
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2026-09-06 Rework README status section to describe current state only
    Claude-Session: https://claude.ai/code/session_01W1unHHYvVLaPudw9s5LXnx
2026-09-06 Update WiFi doc for ESP32's native WiFi, drop stale STM32 references
    Replaces the Inventek ISM43362/X-CUBE-WIFI1 plan (external SPI WiFi
    module, needed on the old STM32 board) with ESP-IDF's native
    esp_wifi/esp_http_server, and updates examples/open questions that
    referenced main.c and sensors (accel/gyro, DS18B20) removed when the
    project pivoted to the ESP32 + RS485 design.
    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
2026-09-06 Fix CI: run kicad container as root to avoid checkout EACCES
    kicad/kicad:9.0's default non-root user can't write to the runner's
    host-mounted temp dirs, which actions/checkout and upload-artifact
    need for their state files. That made every run fail before the ERC
    step ever executed. Running the container as root fixes it.
    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
2026-09-06 Fix CI: use KiCad nightly image to read newer schematic format
    hardware/v1/v1.kicad_sch is stamped with schema version 20260306,
    newer than what kicad/kicad:9.0 (stable) ships, so kicad-cli errored
    with "Failed to load schematic". kicad/kicad:nightly tracks the
    latest development build and can read it.
    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
2026-09-06 Fix CI: pin KiCad image to stable 10.0 matching the schematic's format
    v1.kicad_sch was saved by KiCad 10.0.0 (generator_version "10.0"), a
    stable release, not a nightly/dev build. kicad/kicad:nightly still
    couldn't load it, so pin to the matching stable tag instead of
    guessing with nightly.
    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
2026-09-06 CI: only fail KiCad checks on error-severity violations
    The 9 findings on hardware/v1/v1.kicad_sch were all warning-severity
    library-resolution notices (the CI container never had its KiCad
    library tables initialized, and PCM_Espressif is a locally-installed
    library that isn't in any fresh install) rather than schematic
    defects. Drop --exit-code-violations and instead check the JSON
    report ourselves via .github/scripts/kicad-report-has-errors.py,
    which only fails the build on "error" severity. Warnings still print
    to the log for visibility.
    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
2026-09-06 Add weekly scheduled run of KiCad checks against main
    schedule: isn't affected by push/pull_request path filters, so this
    catches drift (e.g. a new default kicad/kicad image) even in weeks
    where nothing under hardware/ changes.
    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
2026-09-06 CI debug: locate KiCad's bundled library table templates
    Temporary discovery step to find where kicad/kicad:10.0 ships its
    default sym-lib-table/fp-lib-table templates, and where a headless
    kicad-cli run looks for the per-profile config dir. Needed to fix the
    "configuration does not include library X" ERC warnings by seeding
    the global library tables the way a first GUI launch normally would.
    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
2026-09-07 CI: seed KiCad's default global library tables
    kicad-cli's headless first run creates a settings dir but never seeds
    sym-lib-table/fp-lib-table the way the GUI's first-run wizard does, so
    every referenced library -- even stock ones like power and
    Interface_UART -- showed up as "not included" in ERC. Copy KiCad's own
    bundled template tables into the profile dir before running ERC/DRC.
    Resolves 7 of the 9 warnings seen on hardware/v1/v1.kicad_sch; the
    remaining 2 (PCM_Espressif) are a locally-installed PCM library that
    isn't part of any stock install and would need to be vendored into the
    repo separately to fully resolve.
    Claude-Session: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
2026-09-07 Fix CI: drop paths filter so the required check always reports
    kicad-checks.yml is a required status check on main, but its paths
    filter meant PRs that don't touch hardware/ (like this one) never
    trigger a run at all -- GitHub shows a required check with no run as
    permanently "pending" and blocks the merge indefinitely. The job only
    takes ~30s, so just run it on every push/PR.
    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
2026-09-07 Rework WiFi plan around MQTT to a Raspberry Pi
    Replace the on-device HTTP server design with MQTT to Mosquitto on a
    Raspberry Pi, with Node-RED as the logic/dashboard layer.
    The previous plan had v1 serving JSON from esp_http_server and MQTT
    arriving only in v2, which made the v1->v2 step a transport rewrite
    rather than a scope increase. It was also the more complex option for
    v1's own goal: an HTTP server needs request handlers and shared state
    between the server and RS485 tasks, where publishing needs neither, and
    it can't carry commands at all without inbound connections to the board.
    docs/wifi.md is restructured accordingly: architecture and topic map are
    hoisted above both versions si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
2026-09-07 Move the command path from v2 into v1
    v1 was scoped as read-only telemetry, with commands arriving alongside
    remote access in v2. Split those apart: commands are orthogonal to where
    the client is standing, so v1 now monitors and controls the tub on the
    LAN and v2 is purely "reach the same thing from outside".
    This makes the version line a single axis — local vs. remote — and
    collapses v2 to a Pi deployment step: with the command path already
    running through the broker in v1, v2 needs no firmware change at all
    (bar optional TLS). The ESP32 is feature-complete at v1.
    Also in v1 as a consequence of taking commands there:
    - Broker and Node-RED dashboard auth move into v1 rather than v2.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
2026-09-07 Make the architecture diagram an editable PNG shown in the README
    The diagram was an XML .drawio file the README could only link to, so it
    never actually appeared anywhere. Replace it with an editable PNG: the
    draw.io XML lives in a zTXt chunk inside the .png, so draw.io opens and
    saves the image round-trip and one file is both the source and the
    rendered diagram.
    This is what makes the README embed possible with no export step and no
    CI. The alternative — keeping the .drawio and generating a PNG in a
    workflow — needs the render committed back by a bot, and a bot push using
    GITHUB_TOKEN doesn't re-trigger checks, which would leave PRs sitting on
    a head commit the required `hardware` che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
2026-09-10 Document the WSL toolchain setup and fix clangd for ESP-IDF
    Development happens in WSL2 with the board attached to the Windows host, so
    its serial port has to be forwarded in with usbipd-win before idf.py can see
    it. docs/wsl-setup.md records that, plus two things that cost real time:
    this machine's IDF was installed with eim, whose export.sh is broken (it
    looks for a virtualenv the installer never creates) -- activate_idf_v6.1.sh
    is the working entry point -- and /dev/ttyUSB0 needs dialout membership,
    which in WSL only takes effect after a `wsl --shutdown`.
    clangd needed three fixes to work against this project at all. Mason's
    clangd is upstream LLVM with no Xtensa backend, so the editor h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
2026-09-10 Add a UART2 loopback test ahead of the RS485 work
    Rename the app source v1.c -> main.c (and point the component registration
    at it), then fill app_main with a bench test that proves the UART path
    before any transceiver is involved: send a known pattern out TX and read it
    back through a jumper between GPIO17 and GPIO16.
    UART2 rather than UART0, which is the console, or UART1, whose default pins
    are wired to the module's SPI flash. The transceiver's DI sits on GPIO17 and
    RO on GPIO16; deliberately not GPIO1/GPIO3, which are hardwired to the
    DevKitC's CP2102N -- driving those would contend with the USB bridge and
    would spray the ROM bootloader's boot banner onto the spa bus at every
    reset, bef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
2026-09-10 Replace the loopback test with an RS485 direction-control test
    Test 1 proved the UART path; this proves the half-duplex direction line,
    which is the last thing verifiable without the spa bus attached.
    GPIO4 goes into uart_set_pin's RTS slot and the port is switched to
    UART_MODE_RS485_HALF_DUPLEX, so the peripheral drives the transceiver's EN
    itself: asserted before the first bit, released only once the last stop bit
    has left the shift register. Toggling a GPIO around uart_write_bytes cannot
    do that -- the call returns when bytes reach the FIFO, not when they reach
    the wire, so a hand-rolled release truncates the tail of every frame.
    Observability drove the loop's shape. Three bytes at 1152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
2026-09-10 Name the RS485 nets and add a pulldown on the direction line
    The schematic connected everything with bare wires and no net labels, so the
    pin assignment lived only in main.c and in the jumper wires on the
    breadboard. Label the five signal nets -- RS485_DI, RS485_RO, RS485_DE,
    RS485_A, RS485_B -- so the GPIO choice is recorded in the hardware source
    rather than inferred from firmware.
    That choice was not arbitrary. GPIO17/16 are UART2's default pins and are
    free on the DevKitC. GPIO1/3 are the obvious-looking candidates, being
    silkscreened TX/RX, and are the wrong answer: they are hardwired to the
    onboard CP2102N, so a transceiver on them contends with the USB bridge, and
    worse, the ROM boot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
    [v1.kicad_sch]
2026-09-10 Name the RS485 constants and split setup out of app_main
    The pin numbers were bare arguments to uart_set_pin, which reads correctly
    only if you remember the parameter order -- a transposition there is silent
    and the loopback test cannot catch it, since a jumper is symmetric. Naming
    them makes the call self-describing and puts the assignment somewhere
    greppable, next to a note on why GPIO1/3 are the wrong answer despite their
    TX/RX silkscreen.
    The idle budget is now derived from the read timeout rather than written as
    50. It only ever meant "five seconds" in combination with the 100ms timeout,
    so the two could drift apart unnoticed.
    Setup moves into rs485_init(). The config, pins, driver an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
2026-09-10 Give J1 a real RJ45 footprint and a bus ground path
    J1 was a two-pin Conn_01x02 carrying only A and B. RS485 is differential but
    not ground-free, so the bus ground reference had no path in the schematic at
    all -- a gap that works on a bench and fails intermittently once installed,
    which is the worst way to find it.
    Replace it with an 8-pin Connector:RJ45, wired A on pin 1, B on pin 2, and
    ground on pin 8. The remaining five are no-connect flagged, so every pin is
    now an explicit decision rather than an omission, and ERC has nothing
    dangling to report.
    The five no-connects also make the safe failure mode the likely one. The
    Balboa topside connector carries ~12V alongside the differential pa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
    [v1.kicad_sch]
2026-09-10 Join the WiFi network at boot
    First half of the link to the Pi. Associates as a station and reports the
    address it gets, so the MQTT client has a network to sit on. Adapted from
    IDF's station example, which is right about the init order and wrong in three
    ways for a board that lives under a hot tub.
    The example gives up permanently after N attempts, which suits a demo that
    reports a result and stops. Here the AP will reboot, drop for a minute, or be
    briefly out of range, and a board that stays dead until someone power-cycles
    it is not acceptable. Retries continue indefinitely, with exponential backoff
    capped at 30s so a genuinely down AP is not hammered. WIFI_FAIL_BIT still
    fires once, only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
2026-09-10 Publish to the broker over MQTT
    Second half of the link to the Pi. Connects to Mosquitto, announces itself,
    and exposes one call for publishing a status blob.
    esp-mqtt is no longer part of ESP-IDF. It shipped in core through 5.x and
    moved out in 6.x, so it arrives as the managed component espressif/mqtt via
    idf_component.yml. Nothing is vendored, but it is a declared dependency now
    rather than something simply present, so dependencies.lock is committed to
    pin the resolved version rather than re-solving on every machine. docs/wifi.md
    said it ships with IDF; corrected.
    The status topic needs both halves to be useful. The LWT covers the board
    vanishing, which is the case that matters, but the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
2026-09-10 Record the V2 module and antenna choice in the roadmap
    The roadmap said "a bare ESP32" without naming a part, leaving the one
    decision that most affects whether V2 works at all unmade and unrecorded.
    Name it as the WROOM-32UE and give the reasoning, because the choice is not
    obvious from a datasheet -- the two variants differ only in the antenna, and
    what settles it is the deployment. A spa equipment bay is water on every side,
    inches of foam, a sealed enclosure the board cannot do without, and an AP
    through an exterior wall. The failure mode is the reason it matters: this
    design depends on holding an outbound MQTT connection, so a weak link does not
    degrade gracefully, it drops and reconne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
2026-09-12 Frame the RS485 bus continuously instead of dumping 2KB once
    Replaces the one-shot capture in app_main with a persistent task that
    reads UART2 forever, splits the stream into Balboa frames, checks each
    CRC, and hands the valid ones up through a callback. Nothing transmits
    yet -- this is the receive half everything else has to sit on.
    Framing per ccutrer/balboa_worldwide_app, which the doc leaves vague and
    lib/bwa/message.rb settles: 7e LL src type[2] payload CRC 7e, where LL
    counts itself, the source, both type bytes, the payload and the CRC but
    not the delimiters, so the frame is LL+2 bytes and the CRC covers the
    LL-1 bytes from the length byte to the last payload byte. CRC-8 with the
    usua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
2026-09-12 Start the RS485 task before bringing up WiFi
    wifi_init_sta blocks on its event group until it either connects or burns
    through FIRST_CONNECT_ATTEMPTS, which with the 1/2/4/8/16s backoff is
    around half a minute against an AP that is down. rs485_start ran after
    it, so a boot with no network meant half a minute of ignoring the spa
    bus entirely.
    The bus is the primary job and has no opinion about WiFi, so it goes
    first. Nothing is lost by publishing early: mqtt_publish_* no-ops while
    the client is NULL, and the connected handler republishes state once the
    link is up.
    Also switches the stats line to PRIu32 and marks the task argument
    unused, so rs485.c compiles warning-free on the host as well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
2026-09-12 Add host tests for the RS485 framer
    The framer is index arithmetic over a protocol whose spec is ambiguous
    about the one detail that matters -- reading it is not the same as
    running it, and a silent off-by-one there looks exactly like a wiring
    fault. make -C firmware/v1/test run compiles rs485.c against stub
    ESP-IDF headers and exercises it over synthetic frames.
    Covered: a no-payload Ready poll at the minimum length, a 24-byte status
    broadcast checked against LL 0x1d and 31 bytes on the wire, two frames
    sharing one delimiter, a flipped CRC, a 0x7e inside a payload, joining
    mid-stream with an impossible length byte, a truncated frame and how
    fast it resyncs, and an oversized length that mus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
2026-09-12 Run the firmware tests and build in CI
    The only CI job was KiCad ERC/DRC, so nothing checked the firmware at
    all: the RS485 framer tests never ran and a compile break could reach
    main unnoticed.
    firmware-tests runs the host framer tests. It needs no toolchain beyond
    stock gcc and finishes in seconds, which is the point -- the framer is
    index arithmetic over a spec that is ambiguous exactly where it matters,
    and this is what stops a silent off-by-one reaching the bus.
    firmware-build compiles against espressif/idf:v6.1, pinned rather than
    release-v6.1 so the image cannot move underneath us. wifi_credentials.h
    is gitignored and both mqtt.c and wifi.c #error without it, so the job
    copies the c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
2026-09-12 Skip the firmware build when no firmware changed
    A README-only PR was pulling a 3-minute ESP-IDF container to compile
    firmware that had not changed. Gating happens at the job level, never
    with a paths filter on the triggers: a required check that never runs
    reports as permanently pending and blocks the merge forever, whereas a
    job skipped by `if:` reports a skipped conclusion that branch protection
    accepts.
    A cheap `changes` job runs always and reports whether firmware/** was
    touched; firmware-build now depends on it. The filter also counts
    ci.yml, so editing the workflow still proves the build works.
    hardware (~45s) and firmware-tests (~3s) stay unconditional. Routing
    them through `change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
2026-09-12 Point the CI badge at the renamed workflow and describe the new jobs
    The badge URL embeds the workflow file name, so renaming kicad-checks.yml
    to ci.yml broke it. Verified the new URL returns 200 and reads "passing".
    The surrounding section had drifted further than the badge: it described
    a workflow that ran on every push, promised a firmware job "once there's
    firmware to build", and named a file that no longer exists. Documents
    firmware-tests and firmware-build, the push/pull_request split and why
    both unrestricted ran everything twice, and the concurrency behaviour.
    Also records why the rename was safe -- a status check's identity comes
    from the job name, not the file name -- since that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
2026-09-12 Document the topside panel interface and supersede the RS485 design
    The tub's topside is a Balboa VL240, and on GS-series packs that panel is
    not on an RS485 bus at all. It's a dumb terminal: the pack owns the logic
    and clocks the 7-segment glass directly over a clock/data pair, while the
    four membrane switches return as raw contacts. Six signals, no addressing,
    no framing, no CRC, nothing to transmit.
    The reverse-engineered Balboa RS485 protocol is real, but it belongs to the
    BP-series systems. The inference that carried it into this project came
    from parts listings rather than from the bus, which is exactly the caveat
    docs/wifi.md already carried.
    Replace the RS485 protocol section with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
2026-09-12 Gate CI on the ESPHome fork so it can't silently stop compiling
    Mirrors firmware-build's changes-filter/gate pattern for
    firmware/esphome-spa/: a config-only edit there can still break the
    vendored esp32-spa.h against a newer ESPHome release, same as it just
    did with the missing text_sensor.h include.
    Claude-Session: https://claude.ai/code/session_01Guo4hrHT4LDJ5iaT5uYcwB
2026-09-12 Switch the ESPHome fork back to Home Assistant instead of MQTT
    Revert api: -> mqtt: from the earlier adaptation: this project now runs
    Home Assistant on the Pi and controls the tub from the HA app, so there's
    no reason to route through Mosquitto/Node-RED for this device. Restores
    upstream's api: block as-is and vendors their spa-control-card.js Lovelace
    card (same pinned commit, MIT), which the earlier MQTT adaptation had no
    use for.
    secrets.yaml.example now asks for api_key (the HA noise-encryption PSK)
    instead of mqtt_broker/mqtt_username/mqtt_password. README documents
    running HA on the Pi alongside Mosquitto and installing the Lovelace card.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
    [esp32-spa.yaml]
2026-09-12 Remove firmware/v1, rename hardware/v1 to hardware/esp32-spa
    firmware/v1 was RS485/esp-mqtt bring-up code for a bus this tub's Mach-7
    pack doesn't actually have (see docs/wifi.md#topside-panel-interface);
    firmware/esphome-spa already replaces it. Deleting it outright rather than
    keeping it around superseded, now that its replacement is in place.
    hardware/v1 is the still-current board (the passive display-tap +
    optocoupler design firmware/esphome-spa targets), just renamed so it isn't
    read as paired with a now-nonexistent firmware/v1. Renamed the KiCad
    project/schematic files to match (esp32-spa.kicad_pro/.kicad_sch) and fixed
    the two internal filename references inside the .kicad_pro so the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
    [esp32-spa.kicad_sch]
2026-09-12 Replace the stale drawio diagrams with Mermaid, redrawn for the current design
    Both docs/*.drawio.png files still drew the superseded RS485/MAX3485
    design (and the IoT one still showed MQTT/Mosquitto/Node-RED in place of
    Home Assistant); the README has been flagging them as stale rather than
    fixing them because editing a drawio-in-PNG file blind, with no way to
    render and check the result here, risked leaving the picture inconsistent
    with its own embedded source.
    Replaced with inline Mermaid diagrams instead: one per hardware revision
    (V1 passive tap, V1.5 +chemistry sensors, V2 custom PCB) plus the IoT
    topology (ESP32 -> Home Assistant, with Mosquitto/Node-RED marked as
    planned rather than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
2026-09-12 Revert "Replace the stale drawio diagrams with Mermaid, redrawn for the current design"
    This reverts commit 743f6e1fe81931c48b57f81a50561c12e4ff430e.
2026-09-12 Patch the drawio diagrams' embedded XML for the current design
    Directly edits the mxGraphModel/mxfile text chunk embedded in each PNG
    (draw.io's own "editable image" format), leaving the raster picture and
    every other PNG byte untouched. The picture won't visually update until
    next opened and re-saved in the draw.io app, but the file is genuinely
    editable there now -- confirmed by decoding the patched chunk back out
    and diffing against the intended XML, and by re-opening both PNGs with
    PIL to confirm the image data itself is unaffected.
    IOT_Architecture.drawio.png: MAX3485/UART half-duplex -> clock/data
    dividers + button optocouplers; Mosquitto's primary role -> Home
    Assistant (ESPHome API,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
2026-09-13 Claim the fork's own project identity in the ESPHome config
    The project: block still reported kgstorm.esp32-spa version 3.2, so Home
    Assistant's device info credited upstream for a config that has since
    diverged (pH/ORP sensing, HA API instead of MQTT). Point the namespace at
    this repo and restart versioning at 1.0 rather than tracking upstream's
    numbering, which no longer describes what is on the device.
    The forked-from header comment and the MIT attribution in LICENSE.upstream
    are untouched; this changes the device identity string, not provenance.
    [esp32-spa.yaml]
2026-09-13 Make the release tag the single source of the firmware version
    Two version numbers could drift apart: the `version` substitution baked
    into the binary and reported to Home Assistant, and the git tag the
    release job names its artifacts after. Tagging v0.2 would have published
    esp32-spa-v0.2.factory.bin containing a firmware that introduces itself
    as whatever the YAML last said, with nothing to flag the mismatch.
    Pass the tag into the release build with -s so the reported version and
    the artifact name always agree. The value in the YAML stays as the default
    for local builds. Only the release job takes the override; the CI gate
    builds from branches where the ref is not a version tag.
    Drop tha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
    [esp32-spa.yaml]
